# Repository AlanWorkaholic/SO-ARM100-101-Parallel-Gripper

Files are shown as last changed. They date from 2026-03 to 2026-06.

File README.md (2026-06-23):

# SO-ARM100/101 Parallel Gripper

<div align="center">

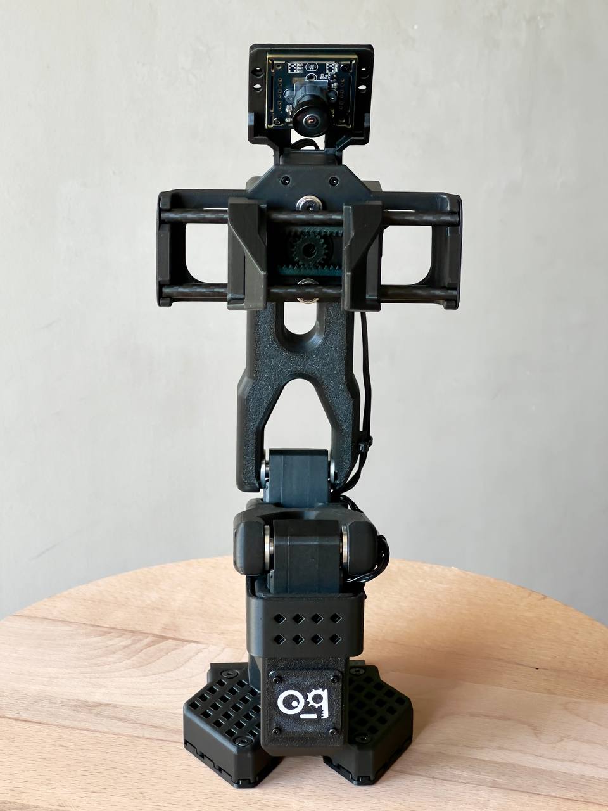
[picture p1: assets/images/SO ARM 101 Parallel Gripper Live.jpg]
SO-ARM101 Parallel Gripper (https://youtube.com/shorts/bSyXjgNGXZk)


**🎥 [Watch the gripper in action!](https://youtube.com/shorts/bSyXjgNGXZk)**

A lightweight 3D-printed parallel gripper designed by **[Robonine](https://robonine.com)** for the open-source SO-ARM100/101 robotic platform.





---

**Questions? We're here to help!**
📩 Email: [hello@robonine.com](mailto:hello@robonine.com)

</div>

---

## ✨ Key Features

| Feature | Description |
|---|---|
| **120N Gripping Force** | Reliable parallel jaw mechanism |
| **14 mm/s Speed** | Gripper operation speed |
| **84mm Full Stroke** | Wide opening for various objects |
| **0.5mm Repeatability** | High precision positioning |
| **Camera Compatible** | Supports RealSense, Orbbec, USB cameras |
| **3D Printable** | All parts print on standard FDM printers |
| **~$62 Total Cost** | Affordable open-source solution |
| **Easy Assembly** | 30-45 minutes with basic tools |

---

## 📸 Gallery

<div align="center">

### Gripper on SO-ARM101

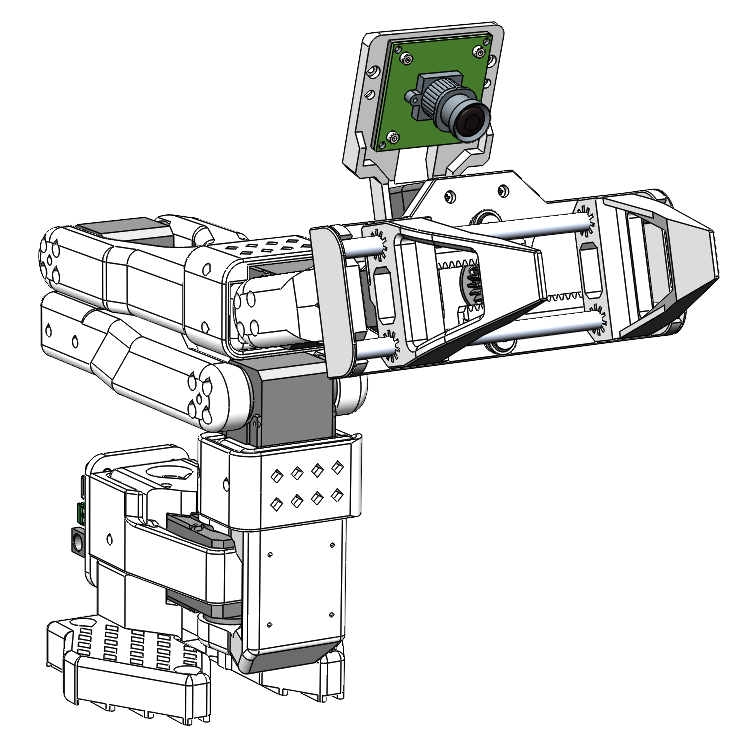
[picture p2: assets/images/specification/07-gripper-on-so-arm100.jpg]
Gripper mounted on SO-ARM101


*Follower gripper integrated with SO-ARM101 robot arm*

### Dimensions

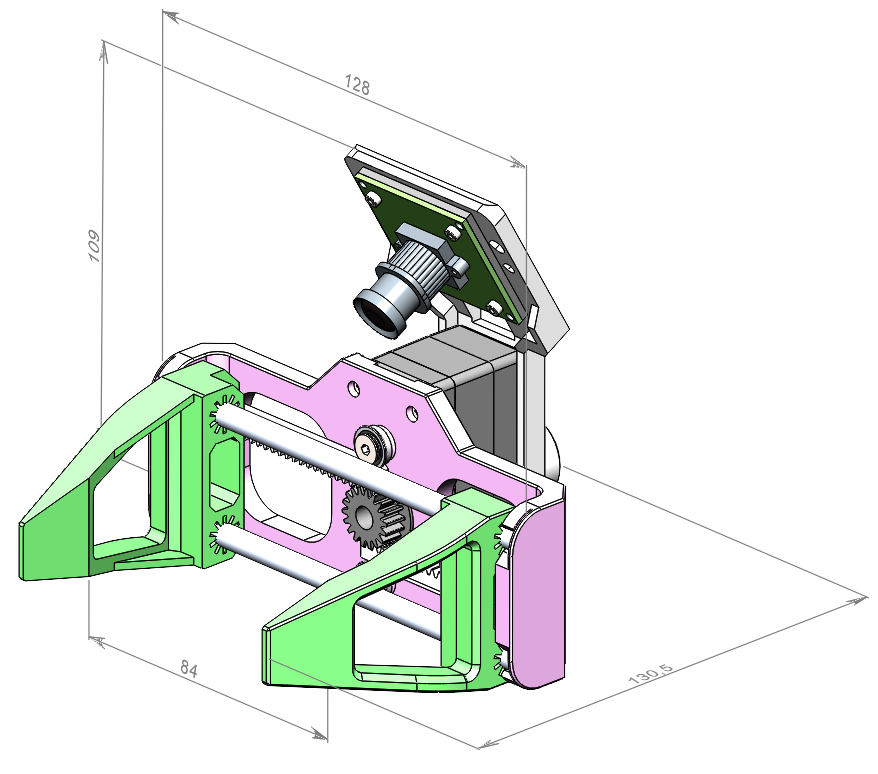
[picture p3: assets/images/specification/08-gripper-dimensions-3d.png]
Gripper dimensions


*128 × 109 × 130.5 mm, full stroke 84 mm*

</div>

---

## 📋 Specifications

### Gripper Parameters

| Parameter | Value |
|---|---|
| Maximum gripping force | **120 N** |
| Maximum gripping speed | **14 mm/s** |
| Full stroke | **84 mm** |
| Repeatability | **0.5 mm** |
| Assembly mass (PLA, 30% infill) | **170 g** |
| DOF | **1** |

### Dimensions

| Dimension | Value |
|---|---|
| Width | 128 mm |
| Depth | 130.5 mm |
| Height | 109 mm |

### Servo Parameters (Feetech STS3215)

| Parameter | Value |
|---|---|
| Operating Voltage | 12V |
| Stall torque | 30 kg·cm |
| Speed (no load) | 45 RPM |
| Encoder | Absolute magnetic 12-bit |
| Protocol | RS485/TTL up to 1 Mbps |
| Operating temperature | -20°C ~ 60°C |

---

## 📷 Camera Compatibility

The gripper supports multiple cameras via interchangeable camera holder:

| Camera | Type | Use Case |
|---|---|---|
| IMX335 5MP USB | RGB | Basic vision tasks |
| GC2093 2MP USB | RGB | Budget option |
| Orbbec Gemini 2 | RGB-D | 3D perception |
| RealSense D405 | RGB-D | Close-range depth |
| RealSense D435/D435i | RGB-D | General purpose |
| RealSense D455 | RGB-D | Long-range depth |

<div align="center">

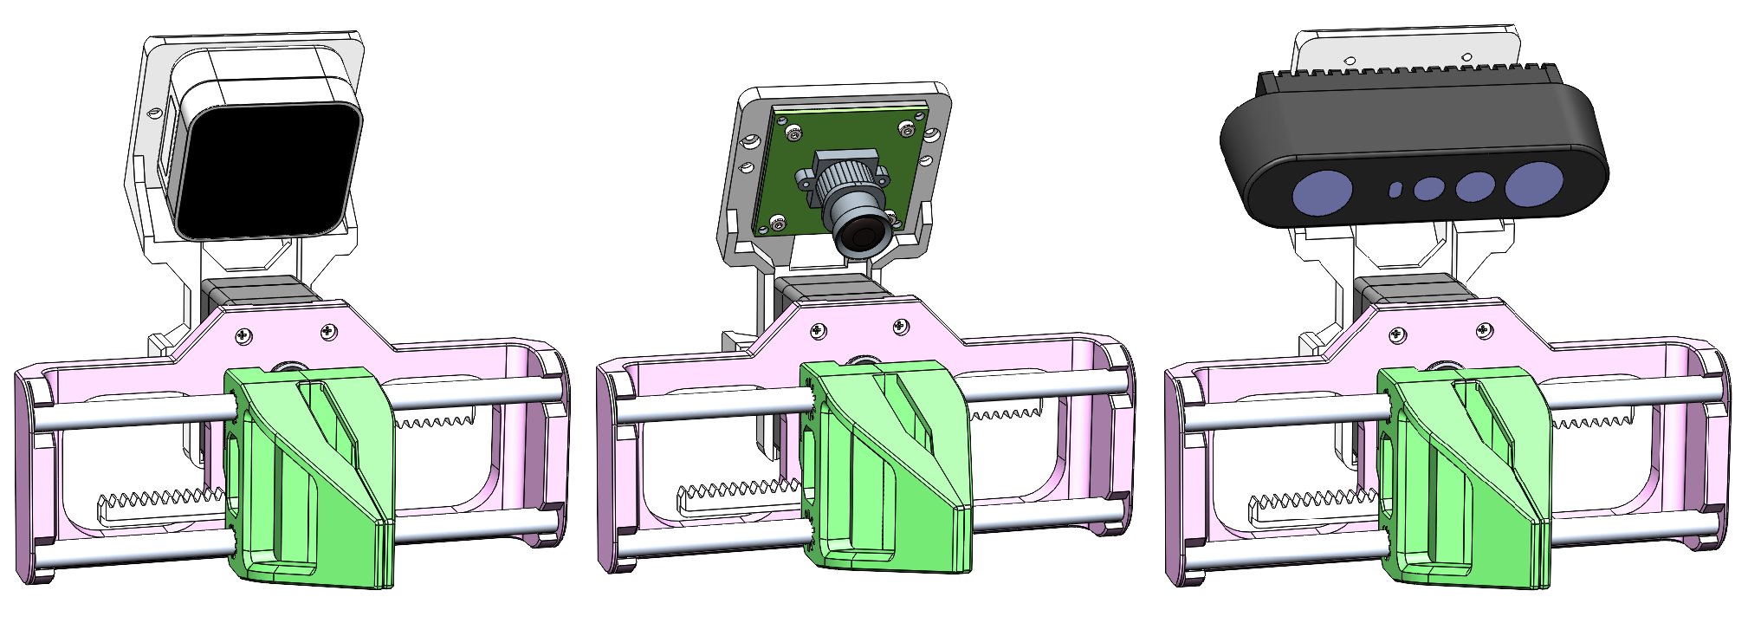
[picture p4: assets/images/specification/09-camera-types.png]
Different cameras mounted on gripper


*RealSense, USB camera module, Orbbec Gemini 2*

</div>

---

## 💰 Bill of Materials

**Total Cost: ~$62** ([Full BOM with Amazon links](docs/bom.md))

| Category | Components | Est. Cost |
|---|---|---|
| Electronics | Feetech STS3215 Servo + Servo Bus Adapter | ~$40 |
| Bearings | MF106ZZ (x2) | ~$2 |
| Aluminium/Carbon Tubes | D6x1×125mm (x2) | ~$4 |
| 3D Printing | 8 parts (~100-150g PLA) | ~$12 |
| Fasteners | M2/M4 screws, M2 nuts, M3 set screws | ~$3 |

---

## 🚀 Quick Start

### 1. Print the Parts (2-4 hours)

Download STL files from [`models/parts/`](models/). Compatible with popular printers like **Bambu Lab A1 mini**, **Prusa MINI+**, and any printer with ≥180×180mm bed.

| Part | Qty | Settings |
|---|:---:|---|
| Main frame (RB9.01.062.010) | 1 | 20% infill |
| Clamp (RB9.01.062.020) | 2 | 20% infill |
| Gear rack (RB9.01.062.030) | 2 | 100% infill |
| Gear (RB9.01.062.040) | 1 | 100% infill |
| Camera holder (RB9.01.060.074) | 1 | 20% infill |
| Holder (RB9.01.060.080) | 1 | 20% infill |
| Camera Spacer (RB9.01.060.090) | 1 | 20% infill |
| D405 holder (RB9.01.060.110) | 1 | 20% infill |

### 2. Order Components (1-2 days)

See [Bill of Materials](docs/bom.md) for direct Amazon links.

### 3. Assemble (30-45 minutes)

Follow the [Assembly Guide](docs/assembly-guide.md) with step-by-step images:

1. Mount gear on servo disc, install this assembly on servo
2. Insert servo cable
3. Using Feetech software move servo to its minimal position (move the slider in the software to the left)
4. Attach gear racks to clamps
5. Inserts the rods into both clamps
6. Install bearings on main frame and fix with srews
7. Snap the rods into the frame
8. Spread the clamps to the extreme positions on the left and right
9. Insert servo and fix it with screws
10. Attach Camera Spacer and UVC camera, fix with 4x screws and nuts M2 (optional)
11. Mount to robot arm (optional)

### 4. Software Setup

```bash
# Install STServo SDK
git clone https://github.com/FEETECH-RC/STServo_SDK_Python.git

# Install dependencies
pip install pyserial

# Run gripper control
python software/python/gripper_control.py
```

---

## 📁 Repository Structure

```
├── assets/
│   └── images/
│       ├── assembly/          # Assembly step images
│       └── specification/     # Technical drawings
├── docs/
│   ├── assembly-guide.md                # Step-by-step assembly
│   ├── bom.md                           # Bill of materials with links
│   ├── Parallel gripper by Robo9.pdf    # Gripper product specification
│   ├── quick-start.md                   # Getting started guide
│   ├── SO-ARM101 by Robo9.pdf           # SO-ARM101 product specification
│   └── specifications.md               # Technical specifications
├── models/
│   ├── parts/                              # Individual STL files
│   └── Follower_Gripper_180x180_BedSize.STL  # Complete assembly (180×180mm bed)
├── simulation/
│   ├── README.md                  # Simulation overview
│   ├── gazebo/                    # Gazebo guide
│   ├── mujoco/                    # MuJoCo guide
│   ├── webots/                    # Webots guide
│   ├── coppeliasim/               # CoppeliaSim guide
│   ├── isaac_sim/                 # Isaac Sim guide
│   └── so_arm_101_description/    # ROS2 package (URDF, launch, Docker)
├── software/
│   └── python/                # Control software
└── examples/                  # Usage examples
```

---

## 📖 Documentation

| Document | Description |
|---|---|
| [Quick Start Guide](docs/quick-start.md) | Get running in 30 minutes |
| [Assembly Guide](docs/assembly-guide.md) | Step-by-step with images |
| [Bill of Materials](docs/bom.md) | Parts list with Amazon links |
| [Specifications](docs/specifications.md) | Technical details |
| [3D Models](models/README.md) | Print settings and files |
| [Parallel Gripper Product Spec (PDF)](docs/Parallel%20gripper%20by%20Robo9.pdf) | Parallel gripper product specification by Robo9 |
| [SO-ARM101 Product Spec (PDF)](docs/SO-ARM101%20by%20Robo9.pdf) | SO-ARM101 robot arm product specification by Robo9 |

---

## 🔧 Hardware Requirements

### Electronics
- 1× Feetech STS3215 Servo Motor
- 1× Bus Servo Adapter Board (Waveshare)

### Mechanical
- 2× MF106ZZ Bearings (6×10×3 mm)
- 2× Aluminium/Carbon Tubes D6x1×125 mm

### Fasteners
- 2× M4×8 DIN 7991 screws
- 4x M2x8 DIN 912 screws
- 4× M2 DIN 934 nuts
- 4× M3×4 DIN 913 set screws

### Tools Required
- Phillips head screwdriver (PH1)
- Hex keys M2 (H1.5) and M4 (H2.5)

---

## 🖥️ Simulation

The SO-ARM101 can be simulated in 5 physics engines using a ROS2 description package with a single parameterized URDF. No ROS2 installation required -- Docker handles everything.

<div align="center">

| Gazebo (Ignition Fortress) | MuJoCo |
|:-:|:-:|
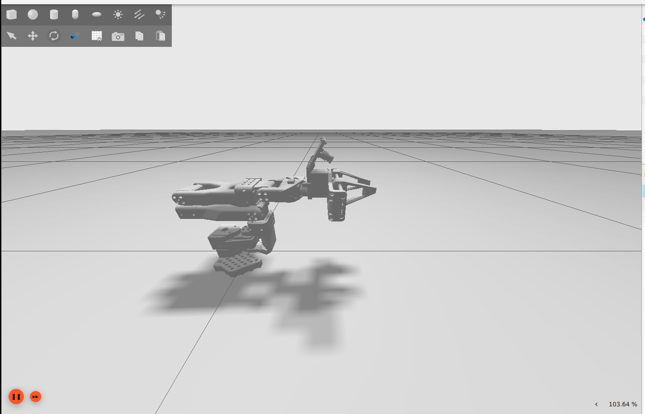
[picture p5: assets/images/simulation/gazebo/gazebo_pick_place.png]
SO-ARM-101 in Gazebo
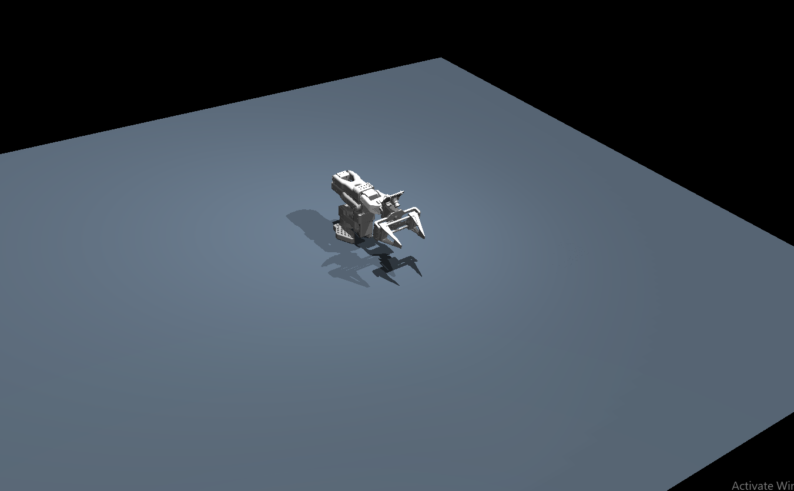
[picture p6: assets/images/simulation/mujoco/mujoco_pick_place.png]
SO-ARM-101 in MuJoCo
|  |  |

</div>

| Simulator | Status | Docker |
|---|---|---|
| [Gazebo](simulation/gazebo/README.md) | Ready | `docker compose run gazebo` |
| [MuJoCo](simulation/mujoco/README.md) | Ready | `docker compose run mujoco` |
| [Webots](simulation/webots/README.md) | Unstable | `docker compose run webots` |
| [CoppeliaSim](simulation/coppeliasim/README.md) | Not tested | External simulator |
| [NVIDIA Isaac Sim](simulation/isaac_sim/README.md) | Not tested | External simulator |

**Quick start (Docker):**

```bash
cd simulation/so_arm_101_description
docker compose run gazebo    # or mujoco, webots
```

See the [Simulation Guide](simulation/README.md) for full setup, architecture details, and robot commanding.

---

## 🤝 Contributing

We welcome contributions! Please feel free to:
- 🐛 Report bugs and issues
- 💡 Suggest new features
- 🔧 Submit pull requests
- 📖 Improve documentation

---

## 📄 License

This project is licensed under the GPL-3.0 License - see the [LICENSE](LICENSE) file for details.

---

## 🔗 Links

- [Feetech STS3215 Servo](https://www.feetechrc.com/525603.html)
- [Waveshare Bus Servo Adapter](https://www.waveshare.com/bus-servo-adapter-a.htm)
- [STServo Python SDK](https://github.com/FEETECH-RC/STServo_SDK_Python)

---

## 👥 Engineering Team

| Name | Role | Contact |
|---|---|---|
| **Boris Kotov** | Software Engineer | [Telegram](https://t.me/bkotov) |
| **Alan Subin** | Design Engineer | [LinkedIn](https://www.linkedin.com/in/alan-subin/) |

---

<div align="center">

**Built for the robotics community by [Robonine](https://robonine.com)** 🤖

**Questions? We're here to help!**
📩 Email: [hello@robonine.com](mailto:hello@robonine.com)

</div>

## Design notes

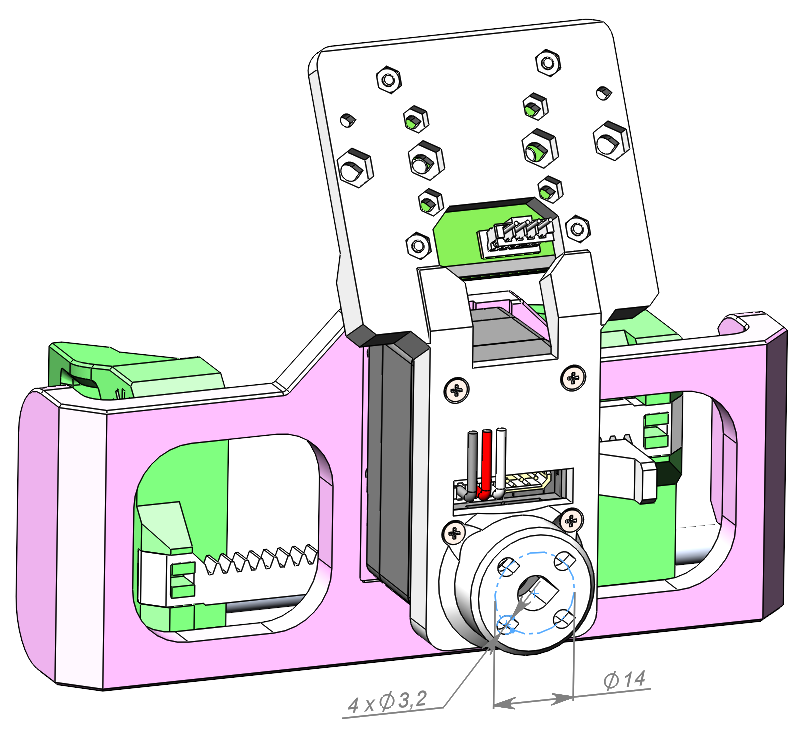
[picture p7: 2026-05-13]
assets/images/specification/03-mounting-interface.jpg

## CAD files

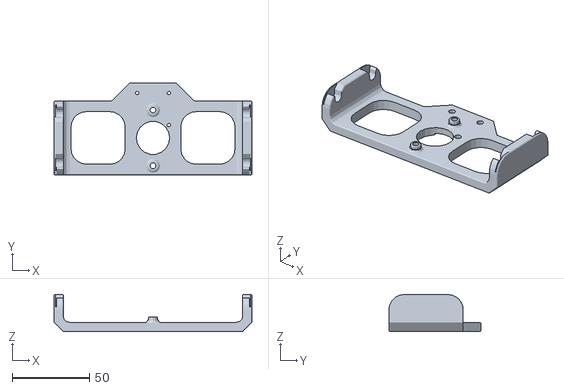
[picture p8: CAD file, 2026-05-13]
models/parts/RB9.01.062.010 Main frame.STL
128.0 x 59.5 x 24.0

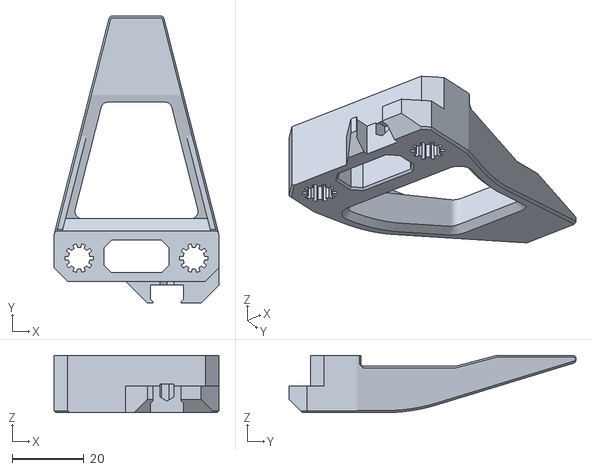
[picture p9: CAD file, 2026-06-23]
models/parts/RB9.01.062.021 (D6.0) Clamp.STL
46.0 x 80.0 x 16.0

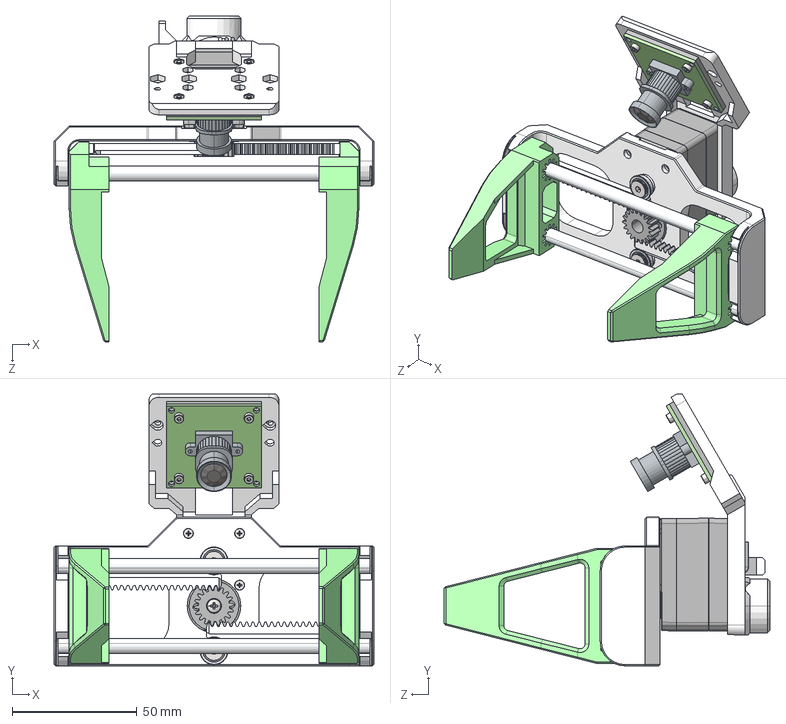
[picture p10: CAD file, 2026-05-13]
models/RB9.01.062.000 Gripper.STEP
128.0 x 108.8 x 130.5 mm
RB9.01.062.010 Main frame_125 follower
RB9.01.062.020 Clamp x 2
RB9.01.062.030 Gear rack_m0.8 x 2
RB9.01.062.040 Gear for gripper_ISO - Spur gear 0.8M 18T 20PA 5FW ---S18B10H8L6.0S1
RB9.01.062.070 Camera holder_follower + camera
RB9.01.060.090 Camera spacer
Rod d6_125 x 2
ZK_122^STS3215_Servo
SG-ZIJI_15^STS3215_Servo
XG-ZIJI_16^STS3215_Servo
Main Wheel^STS3215_Servo
pan head cross recess screw_din_DIN EN ISO 7045 - M3 x 4 - Z - 4N
0050375033_｢ｯ燿｢ｮ
GC2093 2MP USB Camera Module_IMX335 5MP USB Camera
Bearing_MF106 10å6å3 x 2
countersunk flat head cross recess screw_din_DIN EN ISO 7046-1 - M2 x 8 - Z - 8N x 3
socket countersunk head screw_din_DIN 7991 - M4 x 8 --- 8N x 2
hex nut style 1 gradeab_din_Hexagon Nut ISO 4032 - M2 - D - N x 4
socket head cap screw_din_DIN 912 M2 x 8 --- 8N x 4

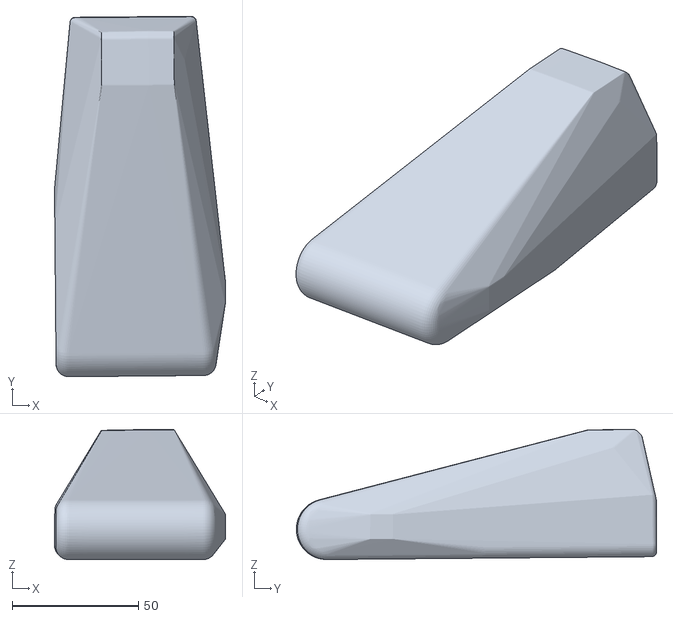
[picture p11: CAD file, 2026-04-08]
simulation/so_arm_101_description/meshes/collision/link2_1.stl
67.7 x 142.7 x 51.5

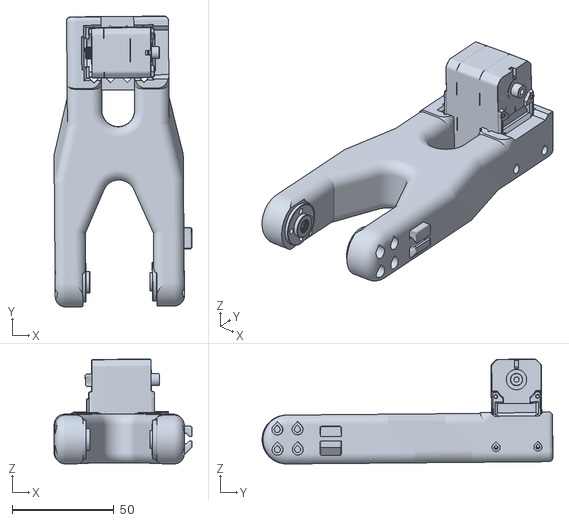
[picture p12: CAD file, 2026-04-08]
simulation/so_arm_101_description/meshes/visual/link2_1.stl
67.7 x 142.7 x 51.5

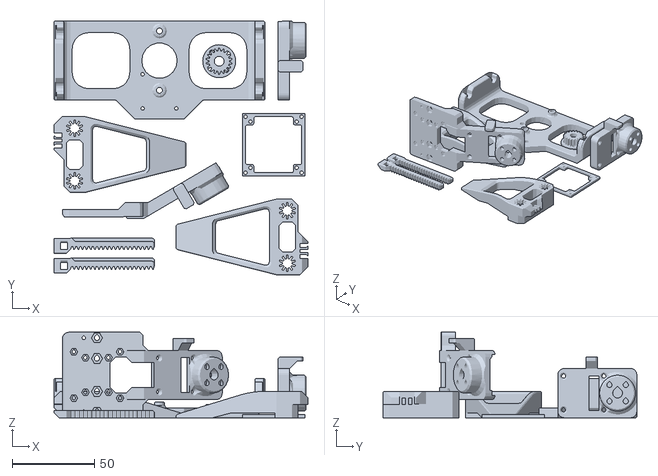
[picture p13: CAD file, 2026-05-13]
models/Follower gripper (165x165 bed size).STL
154.1 x 154.0 x 52.0

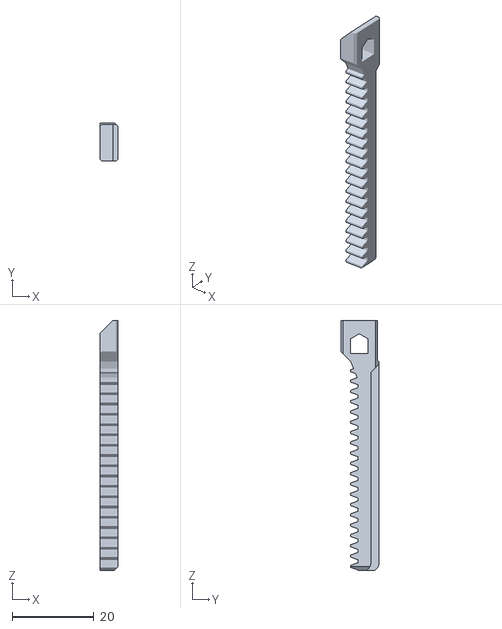
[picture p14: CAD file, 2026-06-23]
models/parts/RB9.01.062.031 Gear rack.STL
4.50 x 9.35 x 61.0

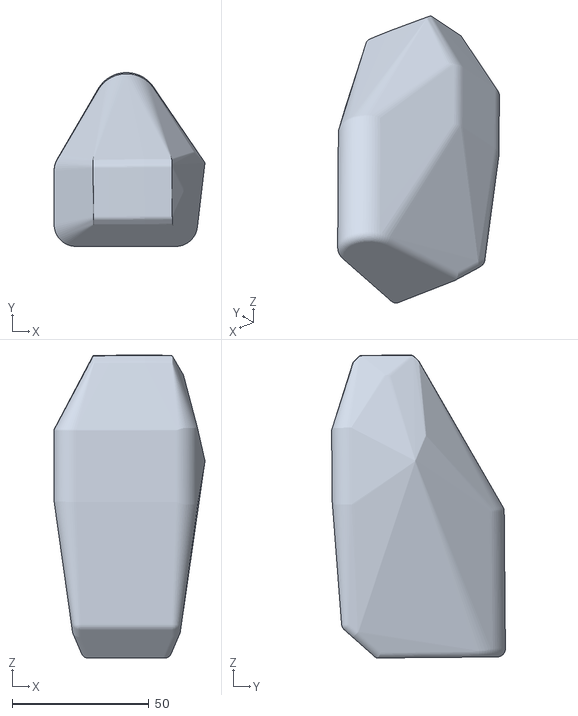
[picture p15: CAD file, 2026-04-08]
simulation/so_arm_101_description/meshes/collision/link1_1.stl
55.1 x 63.5 x 110.7

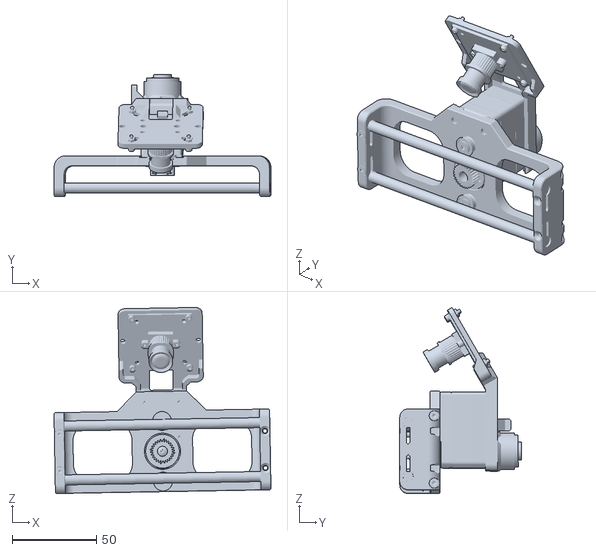
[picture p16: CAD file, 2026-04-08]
simulation/so_arm_101_description/meshes/visual/link5_1.stl
128.8 x 72.5 x 110.5

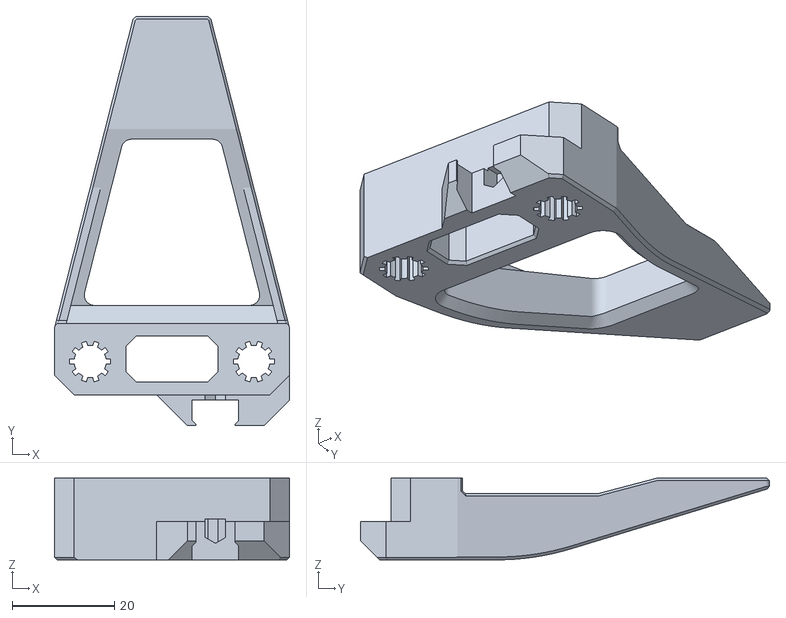
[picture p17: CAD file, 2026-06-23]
models/parts/RB9.01.062.021 (D6.3) Clamp.STL
46.0 x 80.0 x 16.0

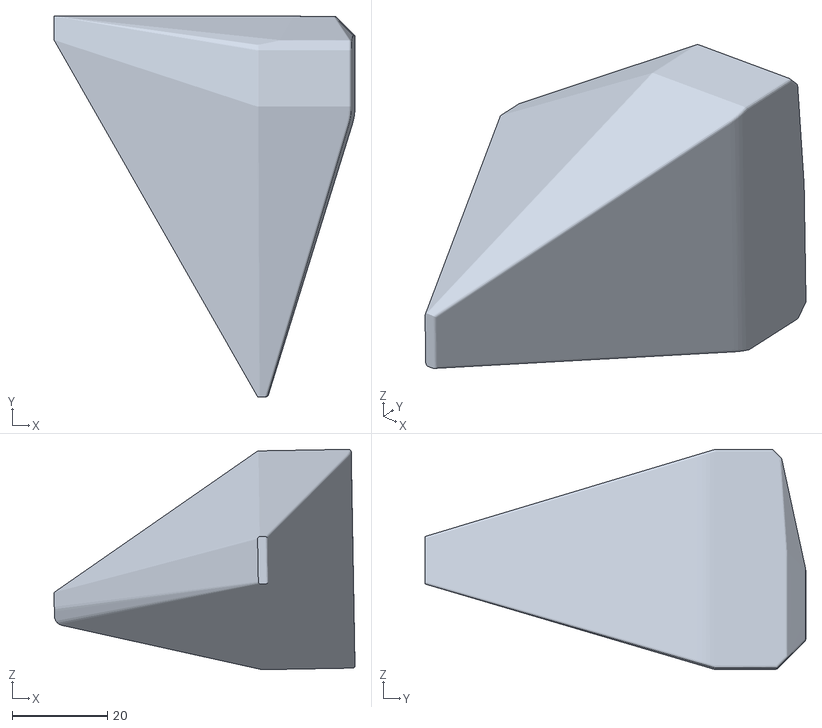
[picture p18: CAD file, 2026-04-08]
simulation/so_arm_101_description/meshes/collision/clamp_1.stl
63.3 x 80.0 x 46.3

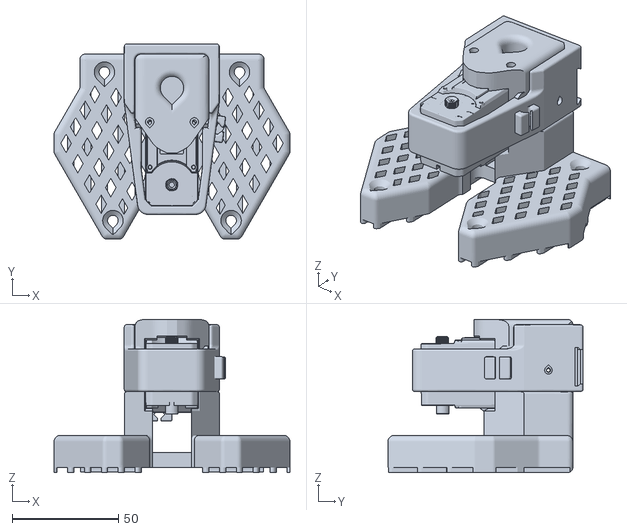
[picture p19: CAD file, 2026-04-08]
simulation/so_arm_101_description/meshes/visual/base_link.stl
110.9 x 91.8 x 72.0

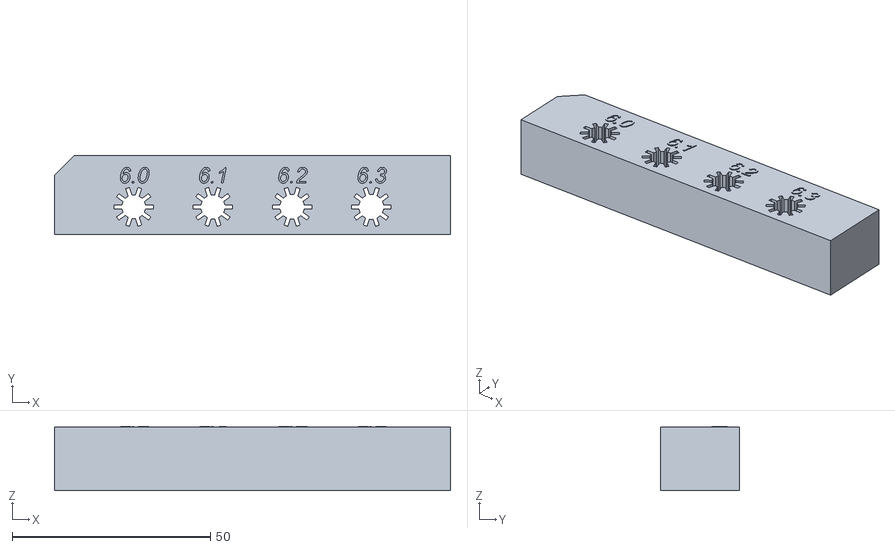
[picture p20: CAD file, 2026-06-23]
models/parts/Gripper test plate star holes 6.0-6.3.STL
100.0 x 20.0 x 16.2

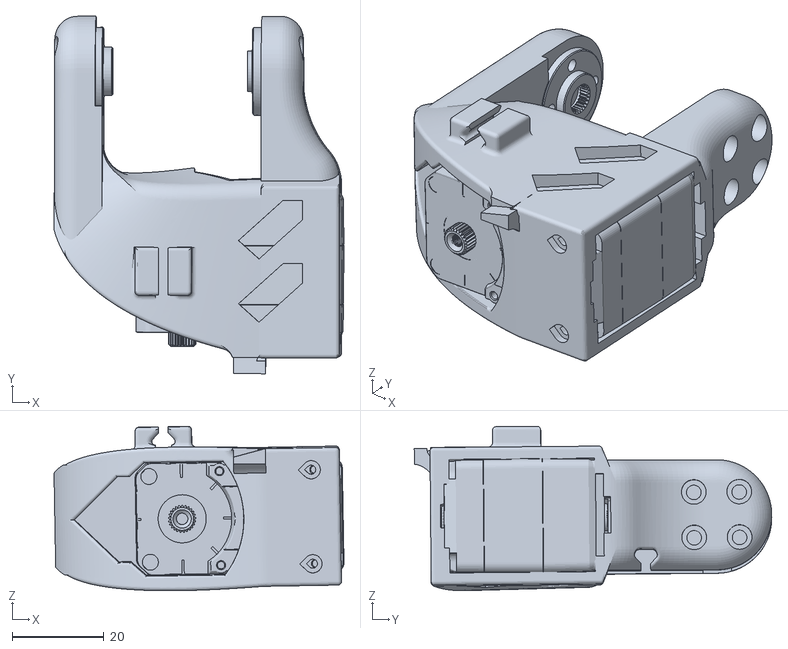
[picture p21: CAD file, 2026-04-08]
simulation/so_arm_101_description/meshes/visual/link4_1.stl
63.2 x 78.0 x 35.9

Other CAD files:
simulation/so_arm_101_description/meshes/collision/clamp_2.stl
models/parts/RB9.01.062.021 (D6.2) Clamp.STL
simulation/so_arm_101_description/meshes/collision/link4_1.stl
simulation/so_arm_101_description/meshes/visual/clamp_2.stl
models/parts/RB9.01.060.074 Camera holder.STL
models/parts/RB9.01.060.080 Holder.STL
models/parts/RB9.01.060.090 Camera spacer.STL
models/parts/RB9.01.060.110 D405 holder.STL
models/parts/RB9.01.062.020 Clamp.STL
models/parts/RB9.01.062.021 (D6.1) Clamp.STL
models/parts/RB9.01.062.030 Gear rack.STL
models/parts/RB9.01.062.040 Gear.STL
models/parts/RB9.01.062.100 Nail.STL
simulation/so_arm_101_description/meshes/collision/base_link.stl
simulation/so_arm_101_description/meshes/collision/link3_1.stl
simulation/so_arm_101_description/meshes/collision/link5_1.stl
simulation/so_arm_101_description/meshes/visual/clamp_1.stl
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

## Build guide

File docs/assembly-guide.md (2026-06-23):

# Assembly Guide for Follower Gripper SO-ARM101

This guide provides step-by-step instructions for assembling the parallel gripper. Follow these steps carefully to ensure proper operation.

## Required Tools

- Phillips head screwdriver PH1
- Hex keys M2 (H1.5) and M4 (H2.5)

---

## Step 1: Install Gear on Servo

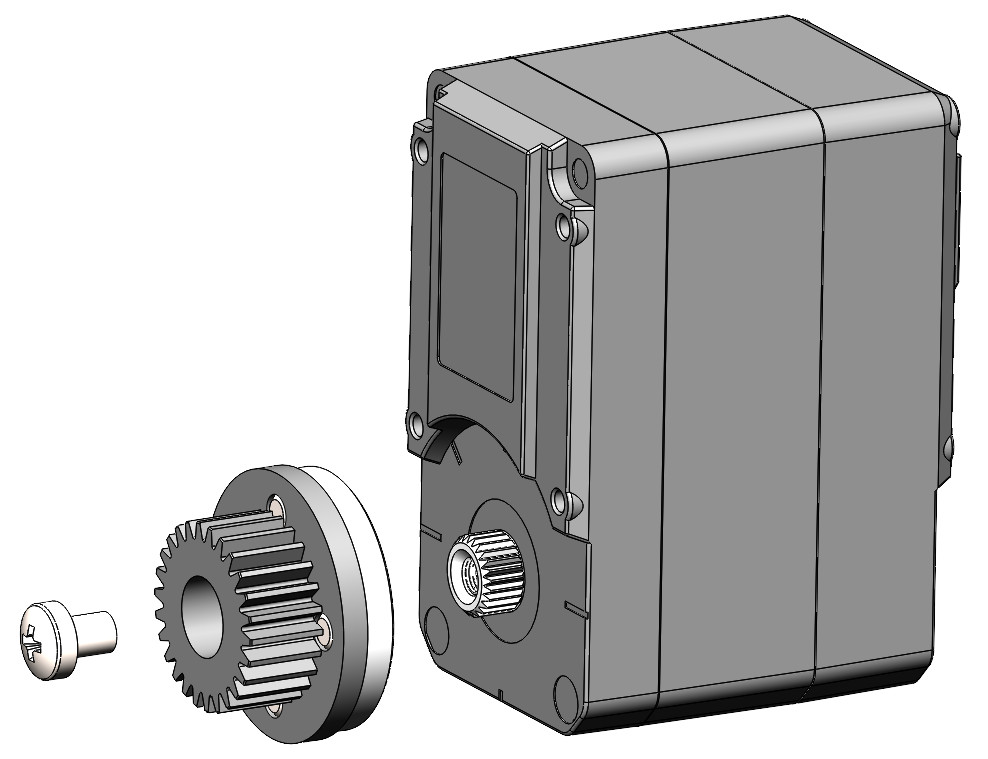
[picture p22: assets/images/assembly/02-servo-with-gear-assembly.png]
Servo with gear assembly


**Components needed:**
- 1x Feetech STS3215 Servo
- 1x Gear  (RB9.01.062.040)
- 1x Servo disk (from servo kit)
- 1x Servo mounting screw M3x6 (from servo kit)
- 4x Set Screw DIN 913 M3x4

**Instructions:**
1. Place Gear for Gripper on Servo disk and tighten 4x Set Screws M3x4 in the direction from Servo disk to Gear. Make sure that no gap appears between Disk and Gear when tightening the screws.
2. Mount the gear assembly onto the servo output shaft.
3. Secure with the screw M3x6 provided in the servo kit.

---

## Step 2: Servo Positioning and Torque Limit

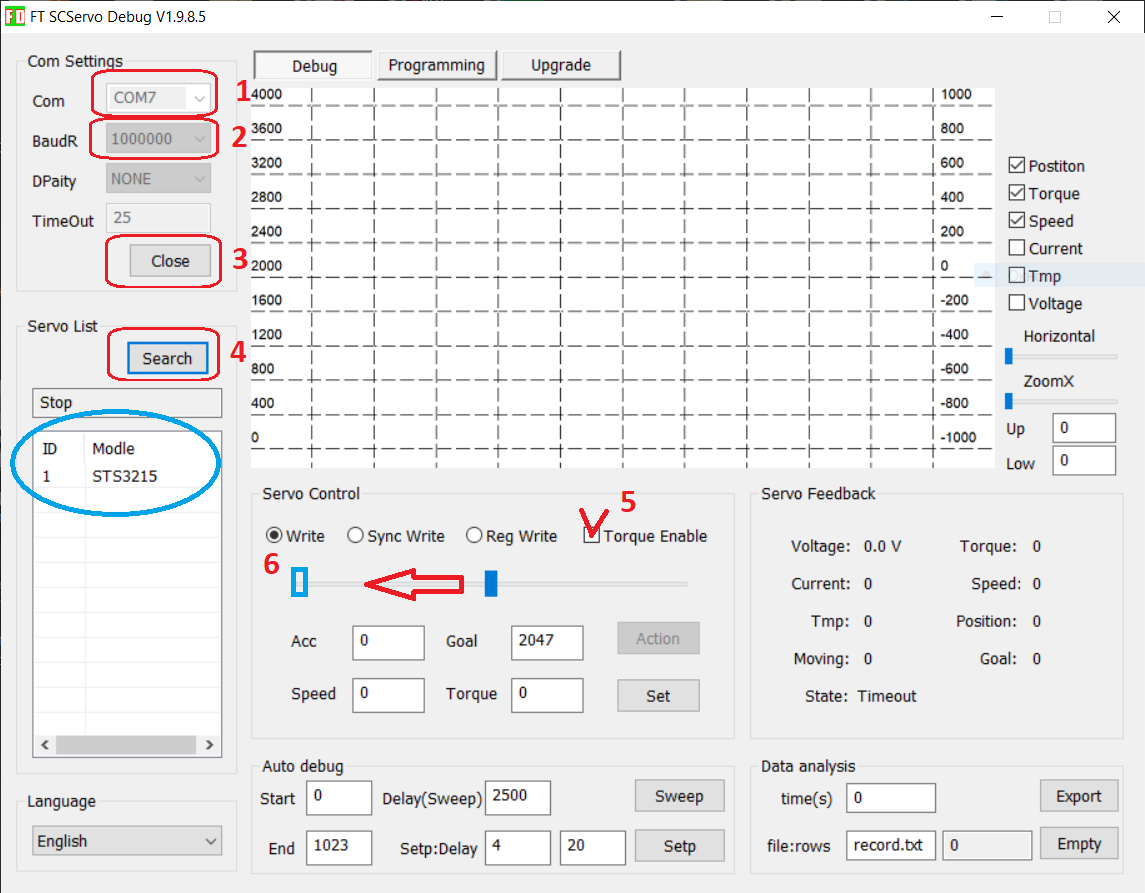
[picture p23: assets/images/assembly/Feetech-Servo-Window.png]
Servo positioning


**Components needed:**
- 1x Serial Bus Servo Board and Cables

**Instructions for Windows users:**
1. Connect Servo to Serial Bus Servo Board, connect Board to PC by USB.
2. Run FD.exe from [`software/python/`](../software/).
3. Choose your COM port, select BaudRate 1 000 000, push buttons "Open" and after "Search".
4. Below from the list select your servo.
5. Check the box to enable torque on servo.
6. Move the slider to the left.

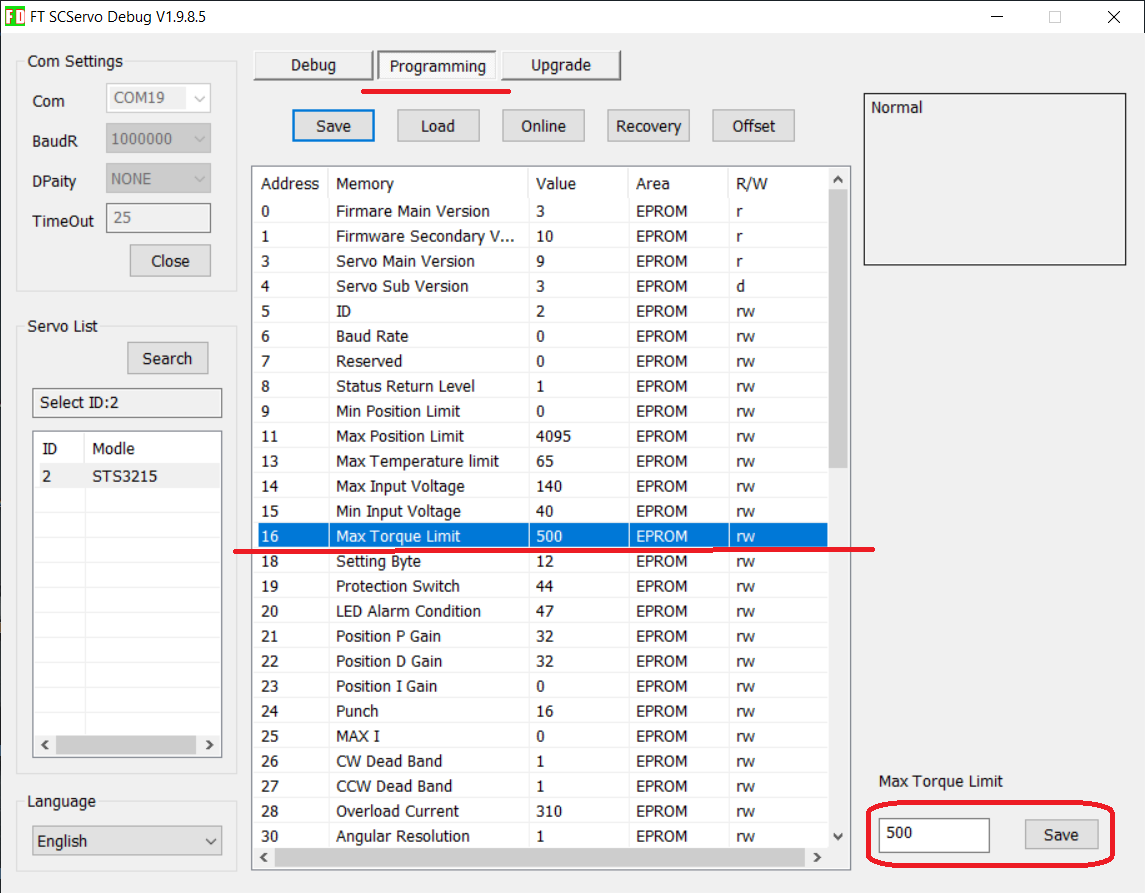
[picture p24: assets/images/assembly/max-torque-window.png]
Max torque limit


7. Switch the window to a tab "Programming".
8. Choose parameter "Max Torque Limit", set it to 500 ans press "Save".

---

## Step 3: Clamps

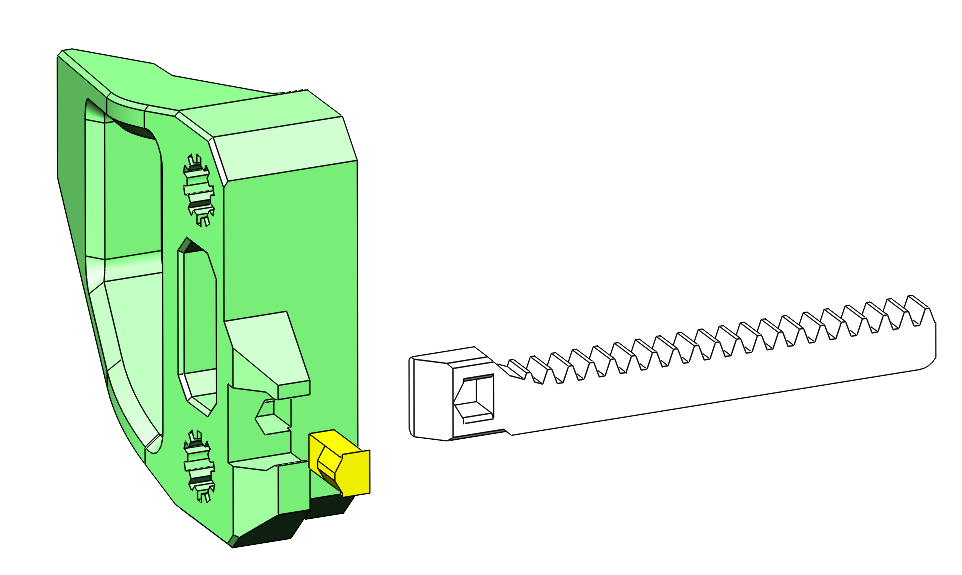
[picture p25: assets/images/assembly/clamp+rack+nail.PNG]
Clamps


**Components needed:**
- 2x Clamps (RB9.01.062.021)
- 2x Gear racks (RB9.01.062.031)
- 2x Nails (RB9.01.062.100)

**Instructions:**
1. Insert gear racks in clamps from side direction.
2. Then insert nails from back direction.

---

## Step 4: Rods

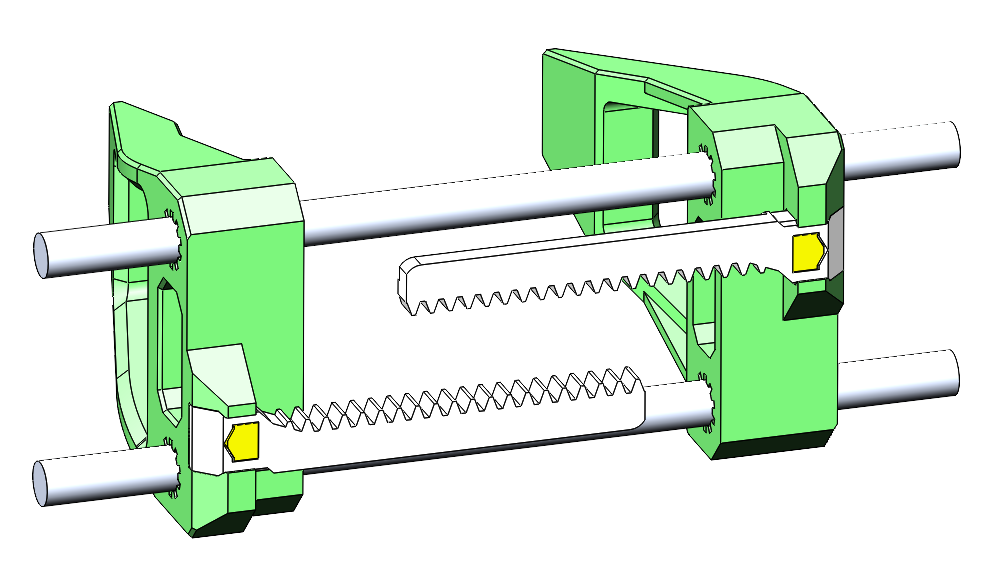
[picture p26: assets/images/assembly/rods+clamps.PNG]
Rods


**Components needed:**
- 2x Rods D6x125mm

**Instructions:**
1. Insert the rods into both clamps. If you ordered rods/tubes longer than 125 mm you need to cut them to this length.

---

## Step 5: Install Bearings on Main Frame

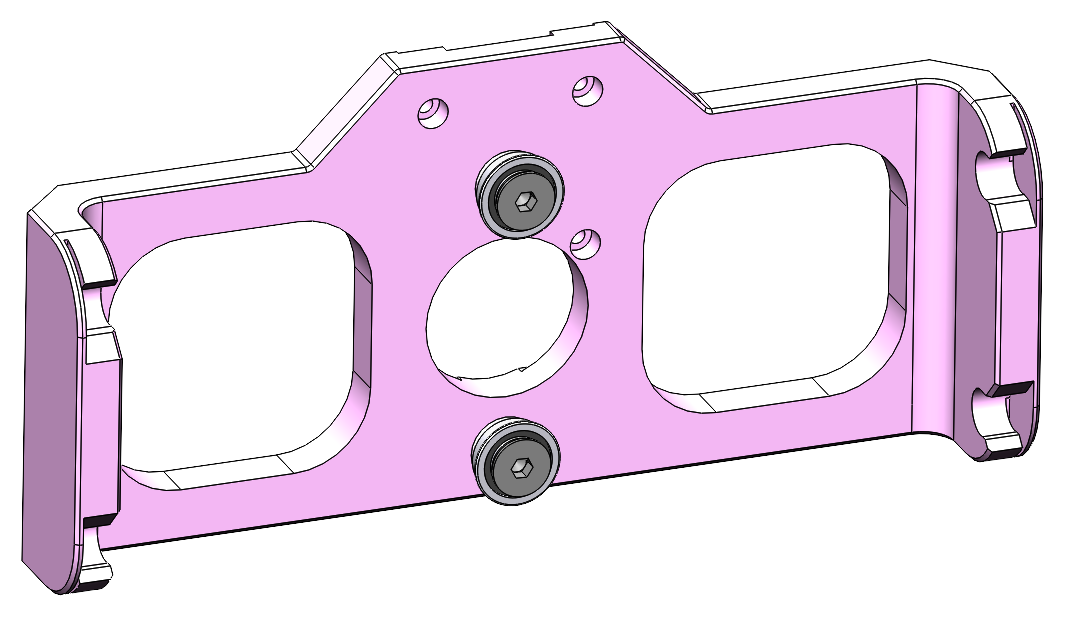
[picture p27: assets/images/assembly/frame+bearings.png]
Bearings installed on main frame


**Components needed:**
- 2x MF106ZZ Bearings (10x6x3 mm)
- 2x M4x8 DIN 7991 screws

**Instructions:**
1. Insert the 2x MF106ZZ bearings into their designated positions on the main frame. Bearing flange should face up.
2. Secure each bearing with screw M4x8.

---

## Step 6: Connection of rods and frame

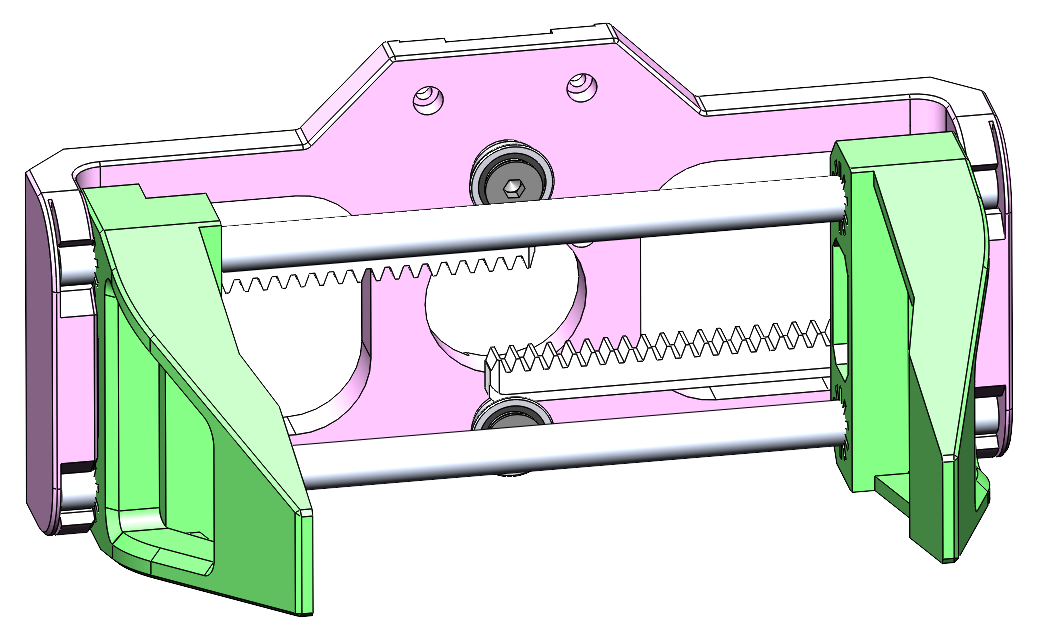
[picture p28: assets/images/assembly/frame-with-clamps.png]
Connection of rods and main frame


**Instructions:**
1. Snap the rods into the frame.
2. Spread the clamps to the extreme positions on the left and right.

---

## Step 7: Mount Servo on Main Frame

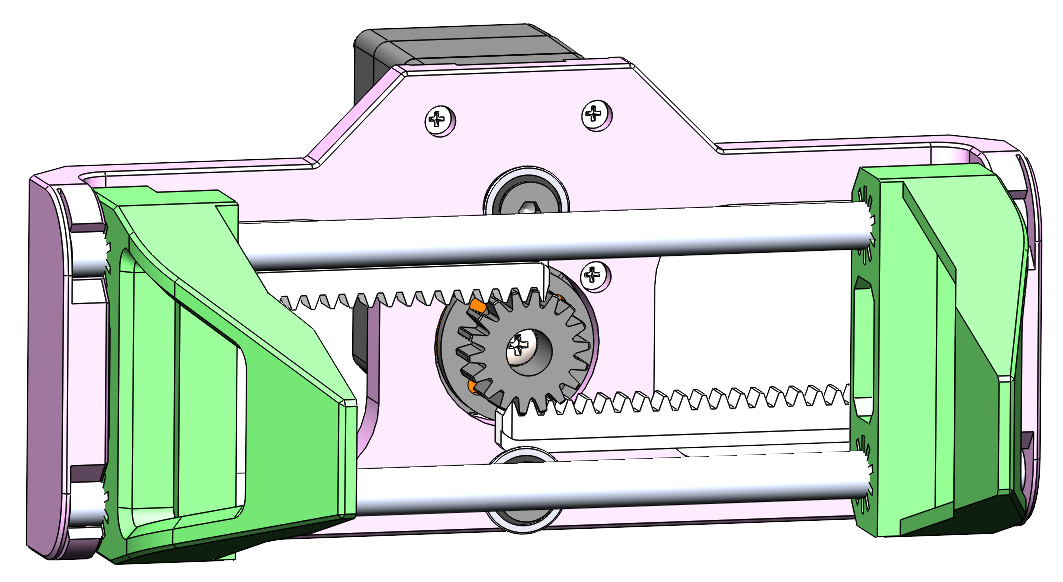
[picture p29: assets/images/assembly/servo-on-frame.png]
Servo mounted on main frame


**Components needed:**
- 3x Self-tapping screws (from servo kit)

**Instructions:**
1. Position the servo on the main frame and align mounting holes.
2. Secure the servo using 3x self-tapping screws from the servo kit.

---

## Step 8: Gripper Holder Attachment

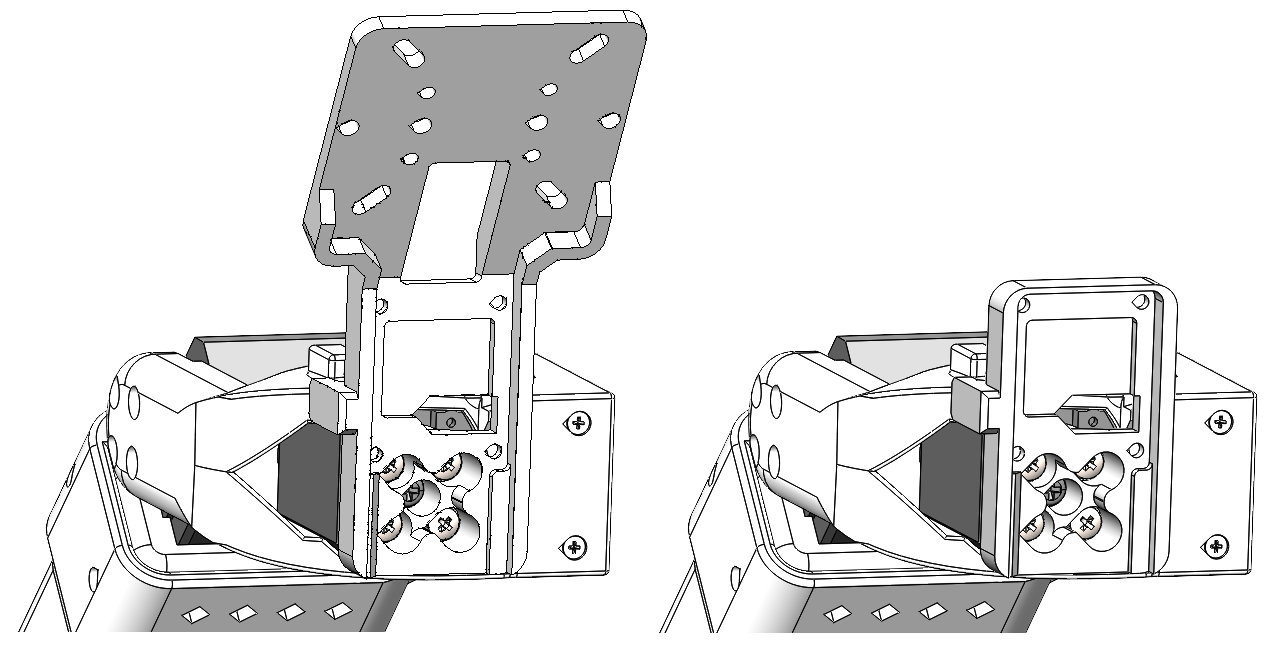
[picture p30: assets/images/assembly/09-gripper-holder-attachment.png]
Gripper holder attachment


**Components needed:**
- 1x Camera holder (RB9.01.060.074) or Holder (RB9.01.060.080)
- 1x SO-ARM101
- 4x M3x6 Screws (from servo kit)
- 4x Self-tapping screws (from servo kit)

**Instructions:**
1. If you plan to use Gripper with camera then attach Camera holder, if you plan to use Gripper without camera then attach Holder to the Wrist Joint horn of SO-ARM101 and fix with 4x M3x6 screws
2. Attach the Parallel Gripper to the Camera holder or Holder and fix with 4x self-tapping screws
3. Connect cable from the Parallel Gripper to servo №5 of SO-ARM101

---

## Step 9: Camera Attachment (optional)

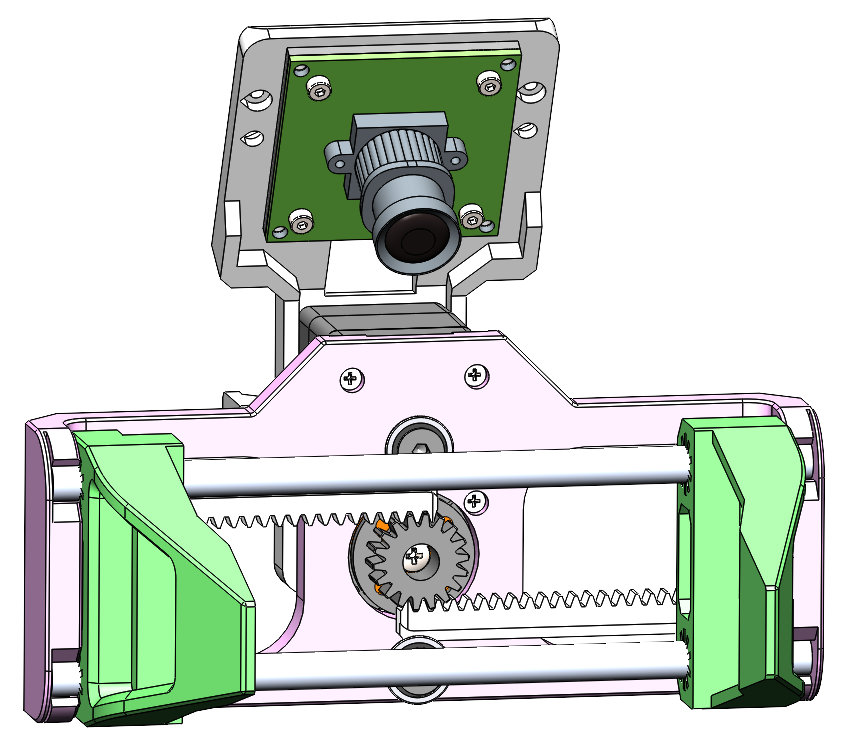
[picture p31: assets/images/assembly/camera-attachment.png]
Camera attachment


**Components needed:**
- 1x UVC Camera with mount holes at 28x28 mm
- 1x Camera Spacer (RB9.01.060.090)
- 4x M2x8 Screws
- 4x M2 Nuts

**Instructions:**
1. Put 4x nuts M2 from the back side of Camera Holder.
2. Put Camera Spacer and Camera from the front side and fix with 4x screws M2x8.

---
## Assembly Complete!

Assembled SO-ARM101 with Follower Gripper

Congratulations! Your SO-ARM101 is now assembled and ready for use.

### Next Steps
- Test gripper operation before use

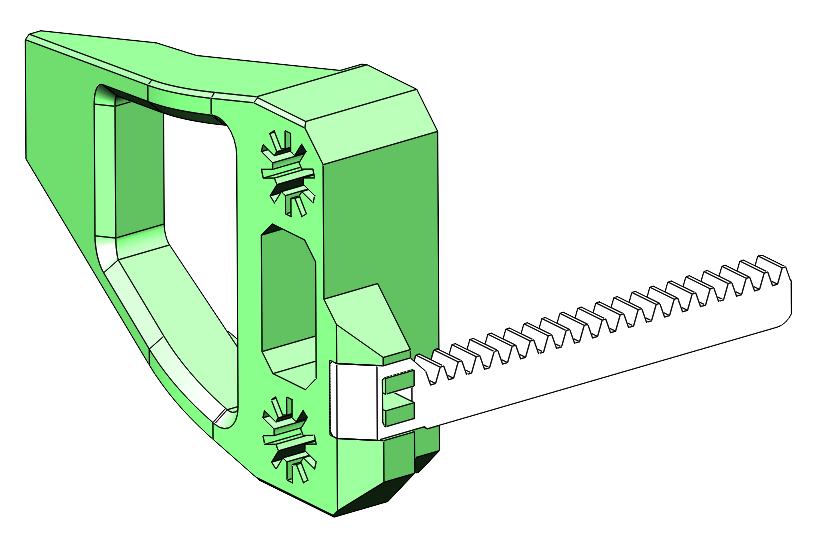
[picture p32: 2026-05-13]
assets/images/assembly/clamp+rack.png

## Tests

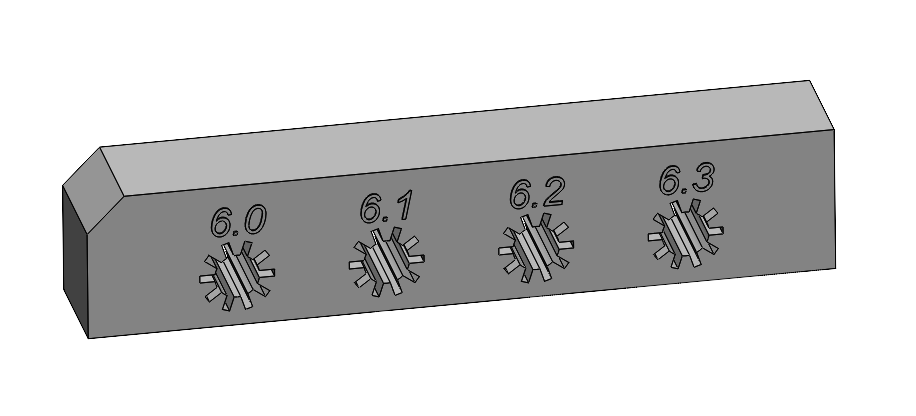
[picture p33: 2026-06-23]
assets/images/assembly/rod-test-plate.PNG

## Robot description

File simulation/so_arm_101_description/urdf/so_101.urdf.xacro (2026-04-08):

<?xml version="1.0" ?>
<robot name="so_101" xmlns:xacro="http://www.ros.org/wiki/xacro">

  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
  <xacro:arg name="sim_backend" default="gazebo"/>

  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
  <xacro:include filename="$(find so_arm_101_description)/urdf/materials.xacro"/>
  <xacro:include filename="$(find so_arm_101_description)/urdf/so_101.ros2_control.xacro"/>

  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
  <mujoco>
    <compiler meshdir="$(find so_arm_101_description)/meshes/collision"/>
  </mujoco>

  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

  <link name="world"/>
  <joint name="world_to_base" type="fixed">
    <parent link="world"/>
    <child link="base_link"/>
    <origin xyz="0 0 0" rpy="0 0 0"/>
  </joint>

  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

  <link name="base_link">
    <inertial>
      <origin xyz="-7.395983749131527e-05 0.018688778123587116 0.031975817456183726" rpy="0 0 0"/>
      <mass value="0.2092095548721987"/>
      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
    </inertial>
    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
  </link>

  <link name="link1_1">
    <inertial>
      <origin xyz="-6.74951590711253e-05 -0.030490405697529033 0.053766555610065915" rpy="0 0 0"/>
      <mass value="0.24184654503223657"/>
      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
    </inertial>
    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
  </link>

  <link name="link2_1">
    <inertial>
      <origin xyz="-0.018388577871412994 0.06261038358877268 0.0010120440807449838" rpy="0 0 0"/>
      <mass value="0.98611438366224"/>
      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
    </inertial>
    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
  </link>

  <link name="link3_1">
    <inertial>
      <origin xyz="-0.017751520535904237 -0.06544031690248904 -0.0001729613192295032" rpy="0 0 0"/>
      <mass value="0.9031154796125306"/>
      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
    </inertial>
    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
  </link>

  <link name="link4_1">
    <inertial>
      <origin xyz="-0.014388616159181473 -0.028802697165152366 -0.00020561897946119734" rpy="0 0 0"/>
      <mass value="0.31773533805976817"/>
      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
    </inertial>
    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
  </link>

  <link name="link5_1">
    <inertial>
      <origin xyz="-0.0005839285183169068 -0.04153912948671028 0.01505583353882603" rpy="0 0 0"/>
      <mass value="0.5561721109318601"/>
      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
    </inertial>
    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
  </link>

  <link name="clamp_1">
    <inertial>
      <origin xyz="0.0601695113719365 0.14480677890200364 0.1844826866723634" rpy="0 0 0"/>
      <mass value="0.15381179772652928"/>
      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
    </inertial>
    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
  </link>

  <link name="clamp_2">
    <inertial>
      <origin xyz="-0.0800042161303889 0.1470101120878245 0.18506826370370444" rpy="0 0 0"/>
      <mass value="0.15381179772652928"/>
      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
    </inertial>
    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
  </link>

  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
  <joint name="base_link_to_link1" type="revolute">
    <origin xyz="-9.9e-05 -0.007243 0.027983" rpy="0 0 0"/>
    <parent link="base_link"/>
    <child link="link1_1"/>
    <axis xyz="-0.0 -0.008727 0.999962"/>
    <limit lower="-2.094395" upper="2.094395" effort="1.5" velocity="5.236"/>
    <dynamics damping="0.1" friction="0.05"/>
    <safety_controller soft_lower_limit="-2.044" soft_upper_limit="2.044" k_position="100" k_velocity="10"/>
  </joint>

  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
  <joint name="link1_to_link2" type="revolute">
    <origin xyz="0.020891 -0.031313 0.091377" rpy="0 0 0"/>
    <parent link="link1_1"/>
    <child link="link2_1"/>
    <axis xyz="-0.999962 -0.008726 -7.6e-05"/>
    <limit lower="-3.228859" upper="0.174533" effort="1.5" velocity="5.236"/>
    <dynamics damping="0.1" friction="0.05"/>
    <safety_controller soft_lower_limit="-3.179" soft_upper_limit="0.125" k_position="100" k_velocity="10"/>
  </joint>

  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
  <joint name="link2_to_link3" type="revolute">
    <origin xyz="0.00151 0.112435 0.029417" rpy="0 0 0"/>
    <parent link="link2_1"/>
    <child link="link3_1"/>
    <axis xyz="-0.999924 -0.00865 -0.008802"/>
    <limit lower="0.0" upper="3.316126" effort="1.5" velocity="5.236"/>
    <dynamics damping="0.1" friction="0.05"/>
    <safety_controller soft_lower_limit="0.05" soft_upper_limit="3.266" k_position="100" k_velocity="10"/>
  </joint>

  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
  <joint name="link3_to_link4" type="revolute">
    <origin xyz="0.00208 -0.134461 0.00412" rpy="0 0 0"/>
    <parent link="link3_1"/>
    <child link="link4_1"/>
    <axis xyz="-0.999848 0.000153 -0.017451"/>
    <limit lower="-1.658063" upper="1.658063" effort="1.5" velocity="5.236"/>
    <dynamics damping="0.1" friction="0.05"/>
    <safety_controller soft_lower_limit="-1.608" soft_upper_limit="1.608" k_position="100" k_velocity="10"/>
  </joint>

  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
  <joint name="link4_to_link5" type="revolute">
    <origin xyz="-0.01732 -0.060045 -0.000831" rpy="0 0 0"/>
    <parent link="link4_1"/>
    <child link="link5_1"/>
    <axis xyz="-1e-06 0.999961 0.008803"/>
    <limit lower="-4.276057" upper="1.570796" effort="1.5" velocity="5.236"/>
    <dynamics damping="0.1" friction="0.05"/>
    <safety_controller soft_lower_limit="-4.226" soft_upper_limit="1.521" k_position="100" k_velocity="10"/>
  </joint>

  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
  <joint name="right_clamp" type="prismatic">
    <origin xyz="-0.052134 -0.220077 -0.186037" rpy="0 0 0"/>
    <parent link="link5_1"/>
    <child link="clamp_1"/>
    <axis xyz="0.999848 -0.000154 0.017451"/>
    <limit lower="0.0" upper="0.037" effort="1.5" velocity="0.05"/>
    <dynamics damping="0.5" friction="0.1"/>
  </joint>

  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
  <joint name="left_clamp" type="prismatic">
    <origin xyz="0.072828 -0.222278 -0.183875" rpy="0 0 0"/>
    <parent link="link5_1"/>
    <child link="clamp_2"/>
    <axis xyz="0.999848 -0.000154 0.017451"/>
    <limit lower="-0.038" upper="0.0" effort="1.5" velocity="0.05"/>
    <dynamics damping="0.5" friction="0.1"/>
    <mimic joint="right_clamp" multiplier="-1" offset="0"/>
  </joint>

</robot>

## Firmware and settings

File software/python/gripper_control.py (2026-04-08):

#!/usr/bin/env python3
"""
Parallel Gripper Control Software
=================================

Professional control software for the open-source parallel gripper using
Feetech STS3215 servo motors. Provides real-time control, monitoring, and
feedback for robotics applications.

Features:
- Precise position control with degree-based input
- Real-time monitoring (position, current, voltage, temperature, load)
- Cross-platform compatibility (Windows, Linux, macOS)
- Interactive control interface
- Comprehensive error handling

Requirements:
- STServo SDK (https://github.com/FEETECH-RC/STServo_SDK_Python)
- Python 3.6+
- Serial communication interface

Author: Open-Source Parallel Gripper Project
License: MIT
"""

import logging
import os
import sys
import time
from pathlib import Path
from typing import Optional, Tuple

import serial.tools.list_ports

# Cross-platform keyboard input handling
if os.name == 'nt':
    import msvcrt
    def getch():
        """Get single character input (Windows)"""
        return msvcrt.getch().decode()
else:
    import termios
    import tty
    def getch():
        """Get single character input (Unix/Linux/macOS)"""
        fd = sys.stdin.fileno()
        old_settings = termios.tcgetattr(fd)
        try:
            tty.setraw(fd)
            return sys.stdin.read(1)
        finally:
            termios.tcsetattr(fd, termios.TCSADRAIN, old_settings)

# Graceful SDK path handling using pathlib
sdk_path = Path(__file__).resolve().parent.parent / "STservo_sdk"
sys.path.append(str(sdk_path))

try:
    from STservo_sdk import *
except ImportError:
    print("Error: STServo SDK not found!")
    print("Please install STServo SDK from: https://github.com/FEETECH-RC/STServo_SDK_Python")
    print("Copy the STservo_sdk folder to your project directory or Python path.")
    sys.exit(1)

# Dynamic COM port selection
print("\n🔌 Available COM ports:")
ports = list(serial.tools.list_ports.comports())
if not ports:
    print("❌ No COM ports found. Please connect your device and try again.")
    sys.exit(1)
for idx, port in enumerate(ports):
    print(f"  [{idx}] {port.device}")

choice = input("Select port number (default 0): ").strip()
SELECTED_PORT = ports[int(choice)].device if choice.isdigit() and int(choice) < len(ports) else ports[0].device

# Configuration Constants
class GripperConfig:
    """Configuration parameters for the parallel gripper"""

    # Servo Configuration
    STS_ID = 1                  # Servo ID (can be changed if multiple servos)
    BAUDRATE = 1000000         # Communication baud rate (1 Mbps)
    DEVICENAME = SELECTED_PORT  # Dynamic port from user selection

    # Motion Parameters
    MAX_DEGREE = 360           # Maximum rotation (degrees)
    MAX_POSITION = 4095        # Maximum position value (12-bit resolution)
    DEFAULT_SPEED = 4800       # Default movement speed
    DEFAULT_ACCELERATION = 5   # Default acceleration

    # Monitoring Parameters
    LSB_TO_mA = 2700 / 2047   # Current conversion factor (~1.32 mA per LSB)
    VOLTAGE_SCALE = 0.1       # Voltage scale factor (0.1V per LSB)
    LOAD_SCALE = 100 / 2047   # Load percentage scale factor

    # Safety Limits
    MAX_TEMPERATURE = 70      # Maximum safe temperature (°C)
    MAX_CURRENT = 2000        # Maximum safe current (mA)

    # Update Intervals
    MONITOR_INTERVAL = 0.05   # Monitoring update interval (seconds)

class ParallelGripper:
    """
    Main class for controlling the parallel gripper

    Provides high-level interface for gripper control, monitoring, and safety.
    """

    def __init__(self, config: GripperConfig = None):
        """
        Initialize the gripper controller

        Args:
            config: Configuration object (uses default if None)
        """
        self.config = config or GripperConfig()
        self.port_handler = None
        self.packet_handler = None
        self.is_connected = False

        # Setup logging
        logging.basicConfig(level=logging.INFO,
                          format='%(asctime)s - %(levelname)s - %(message)s')
        self.logger = logging.getLogger(__name__)

    def connect(self) -> bool:
        """
        Establish connection to the servo

        Returns:
            bool: True if connection successful, False otherwise
        """
        try:
            self.port_handler = PortHandler(self.config.DEVICENAME)
            self.packet_handler = sts(self.port_handler)

            if not self.port_handler.openPort():
                self.logger.error(f"Failed to open port {self.config.DEVICENAME}")
                return False

            if not self.port_handler.setBaudRate(self.config.BAUDRATE):
                self.logger.error(f"Failed to set baud rate to {self.config.BAUDRATE}")
                return False

            # Set servo to position control mode
            self.packet_handler.write1ByteTxRx(self.config.STS_ID, 33, 0)

            self.is_connected = True
            self.logger.info(f"Connected to servo ID {self.config.STS_ID} on {self.config.DEVICENAME}")
            return True

        except Exception as e:
            self.logger.error(f"Connection failed: {e}")
            return False

    def disconnect(self):
        """Close the connection to the servo"""
        if self.port_handler and self.is_connected:
            self.port_handler.closePort()
            self.is_connected = False
            self.logger.info("Disconnected from servo")

    def degrees_to_position(self, degrees: float) -> int:
        """
        Convert degrees to servo position value

        Args:
            degrees: Angle in degrees (can be negative)

        Returns:
            int: Servo position value (0-4095)
        """
        degrees = degrees % self.config.MAX_DEGREE
        return int((degrees / self.config.MAX_DEGREE) * self.config.MAX_POSITION)

    def position_to_degrees(self, position: int) -> float:
        """
        Convert servo position value to degrees

        Args:
            position: Servo position value (0-4095)

        Returns:
            float: Angle in degrees
        """
        return (position / self.config.MAX_POSITION) * self.config.MAX_DEGREE

    def move_to_angle(self, angle: float, speed: int = None, acceleration: int = None) -> bool:
        """
        Move gripper to specified angle

        Args:
            angle: Target angle in degrees
            speed: Movement speed (uses default if None)
            acceleration: Movement acceleration (uses default if None)

        Returns:
            bool: True if command sent successfully, False otherwise
        """
        if not self.is_connected:
            self.logger.error("Not connected to servo")
            return False

        speed = speed or self.config.DEFAULT_SPEED
        acceleration = acceleration or self.config.DEFAULT_ACCELERATION

        goal_position = self.degrees_to_position(angle)

        try:
            result, error = self.packet_handler.WritePosEx(
                self.config.STS_ID, goal_position, speed, acceleration
            )

            if result != COMM_SUCCESS:
                self.logger.error(f"Communication error: {self.packet_handler.getTxRxResult(result)}")
                return False

            if error != 0:
                self.logger.error(f"Servo error: {self.packet_handler.getRxPacketError(error)}")
                return False

            self.logger.info(f"Moving to {angle:.1f}° (position {goal_position})")
            return True

        except Exception as e:
            self.logger.error(f"Move command failed: {e}")
            return False

    def get_status(self) -> Optional[dict]:
        """
        Get current servo status and telemetry

        Returns:
            dict: Status information or None if error
        """
        if not self.is_connected:
            return None

        try:
            # Current position
            position, _, _ = self.packet_handler.ReadPos(self.config.STS_ID)
            degrees = self.position_to_degrees(position)

            # Current draw
            current_raw, _, _ = self.packet_handler.read2ByteTxRx(self.config.STS_ID, 69)
            current = self.packet_handler.sts_tohost(current_raw, 15)
            current_mA = current * self.config.LSB_TO_mA

            # Supply voltage
            voltage_raw, _, _ = self.packet_handler.read1ByteTxRx(self.config.STS_ID, 62)
            voltage = voltage_raw * self.config.VOLTAGE_SCALE

            # Load percentage
            load_raw, _, _ = self.packet_handler.read2ByteTxRx(self.config.STS_ID, 60)
            load_percent = int(round(load_raw * self.config.LOAD_SCALE))

            # Temperature
            temperature, _, _ = self.packet_handler.read1ByteTxRx(self.config.STS_ID, 63)

            # Movement status
            is_moving, _, _ = self.packet_handler.ReadMoving(self.config.STS_ID)

            return {
                'position': position,
                'degrees': degrees,
                'current_raw': current,
                'current_mA': current_mA,
                'voltage': voltage,
                'load_percent': load_percent,
                'temperature': temperature,
                'is_moving': bool(is_moving)
            }

        except Exception as e:
            self.logger.error(f"Status read failed: {e}")
            return None

    def wait_for_completion(self, target_position: int, timeout: float = 10.0) -> bool:
        """
        Wait for movement to complete with real-time monitoring

        Args:
            target_position: Expected final position
            timeout: Maximum wait time in seconds

        Returns:
            bool: True if movement completed successfully
        """
        start_time = time.time()

        print("🟡 Movement in progress... (Press Ctrl+C to stop)\n")

        try:
            while time.time() - start_time < timeout:
                time.sleep(self.config.MONITOR_INTERVAL)

                status = self.get_status()
                if not status:
                    return False

                # Display status
                print(f" → Target: {target_position:4d} | "
                      f"Position: {status['position']:4d} ({status['degrees']:6.1f}°) | "
                      f"Current: {status['current_raw']:3d} ({status['current_mA']:.0f}mA) | "
                      f"Load: {status['load_percent']:2d}% | "
                      f"Temp: {status['temperature']}°C")

                # Safety checks
                if status['temperature'] > self.config.MAX_TEMPERATURE:
                    self.logger.warning(f"High temperature: {status['temperature']}°C")

                if status['current_mA'] > self.config.MAX_CURRENT:
                    self.logger.warning(f"High current: {status['current_mA']:.0f}mA")

                # Check if movement completed
                if not status['is_moving']:
                    print("✅ Movement completed\n")
                    return True

            self.logger.warning("Movement timeout")
            return False

        except KeyboardInterrupt:
            print("\n⏹️ Movement interrupted by user")
            return False

    def interactive_control(self):
        """Run interactive control interface"""
        print("\n" + "="*60)
        print("🤖 PARALLEL GRIPPER CONTROL INTERFACE")
        print("="*60)
        print(f"Servo ID: {self.config.STS_ID}")
        print(f"Port: {self.config.DEVICENAME}")
        print(f"Baud Rate: {self.config.BAUDRATE}")
        print("-"*60)
        print("Commands:")
        print("  • Enter angle in degrees (positive or negative)")
        print("  • Press Enter (empty) to exit")
        print("  • Ctrl+C to interrupt movement")
        print("="*60)

        try:
            while True:
                user_input = input("\nEnter target angle (degrees): ").strip()

                if not user_input:
                    print("👋 Exiting...")
                    break

                try:
                    angle = float(user_input)
                    target_position = self.degrees_to_position(angle)

                    if self.move_to_angle(angle):
                        self.wait_for_completion(target_position)

                except ValueError:
                    print("❌ Invalid input. Please enter a number.")
                except Exception as e:
                    self.logger.error(f"Control error: {e}")

        except KeyboardInterrupt:
            print("\n👋 Control interface interrupted")

def main():
    """Main function - entry point for the application"""
    print("🚀 Starting Parallel Gripper Control Software...")

    # Create gripper instance
    gripper = ParallelGripper()

    try:
        # Connect to servo
        if not gripper.connect():
            print("❌ Failed to connect to servo. Please check:")
            print("  • Port name (currently: {})".format(gripper.config.DEVICENAME))
            print("  • Servo power and connections")
            print("  • Servo ID (currently: {})".format(gripper.config.STS_ID))
            print("  • Baud rate (currently: {})".format(gripper.config.BAUDRATE))
            return 1

        # Run interactive control
        gripper.interactive_control()

    except Exception as e:
        print(f"❌ Unexpected error: {e}")
        return 1

    finally:
        # Ensure clean shutdown
        gripper.disconnect()

    return 0

if __name__ == "__main__":
    sys.exit(main())

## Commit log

2026-02-14 docs: Add Parallel Gripper product spec PDF, update SO-ARM101 spec PDF, and add links across documentation
2026-02-14 docs: Update gripper specs from product specification PDF and add new media assets
2026-02-14 docs: Remove outdated dimension and camera images, update references to new assets
2026-02-14 docs: Update BOM rods, hardware requirements, and dimension naming to match developer README
2026-02-14 docs: Update README to reflect the integration of the gripper with SO-ARM101, including image and description changes
2026-03-31 Update assembly-guide
2026-03-31 picture for Camera Holder and Holder
2026-03-31 deleted old stl models
    [Follower_Gripper_180x180_BedSize.STL, RB9.01.060.015 Main frame 128mm (follower).STL, RB9.01.060.021 Clamp.STL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]
2026-03-31 step and stl all-in-one
    [Follower gripper (140x140 bed size).STL]
2026-04-07 feat: add multi-simulator ROS2 support (Gazebo, MuJoCo, Webots, CoppeliaSim, Isaac Sim)
    Add a complete ROS2 description package with a single parameterized URDF
    that drives 5 physics engines through one launch file.
    - simulation/so_arm_101_description/: full ROS2 package with URDF, meshes,
    controllers, launch files, Dockerfile, and docker-compose
    - Per-simulator READMEs with setup guides, launch instructions, and
    troubleshooting for each backend
    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
    [base_link.stl, clamp_1.stl, clamp_2.stl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]
2026-04-08 chore: add CI/CD pipeline and pre-commit hooks
    - Add GitHub Actions CI with lint, validate, URDF, and test jobs
    - Add .pre-commit-config.yaml (flake8, isort, trailing whitespace, XML)
    - Fix isort import order in simulation launch files
    - Fix trailing whitespace in docs and existing files
    [gripper_control.py]
2026-05-10 removed linear bearings
2026-05-11 Update2 bom.md
2026-05-11 Update3 bom.md
2026-05-13 new assembly pictures
2026-05-13 stl and step for gripper
    [Follower gripper (165x165 bed size).STL, RB9.01.062.000 Gripper.STEP]
2026-05-13 stl for parts
    [RB9.01.060.074 Camera holder.STL, RB9.01.060.080 Holder.STL, RB9.01.060.090 Camera spacer.STL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]
2026-05-13 deleted old stl files
    [Follower gripper (140x140 bed size).STL, RB9.01.061.000 Gripper.STEP, RB9.01.061.010 Main frame.STL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]
2026-05-13 Fix trailing whitespace in assembly guide
2026-05-19 docs: replace main README image with new gripper photo
2026-05-19 docs: update video link to new gripper demo and sync quick-start image
2026-05-20 docs: replace main README image with new gripper photo
    Swap assets/images/SO-ARM-101-Parallel-Gripper.jpg for a new PNG
    and update references in README.md and docs/quick-start.md.
2026-06-01 just one rod
2026-06-23 stl for D405 Holder
    [RB9.01.060.110 D405 holder.STL]
2026-06-23 update 3 cameras picture
2026-06-23 clamps stl files with holes 6.0-6.3
    [Gripper test plate star holes 6.0-6.3.STL, RB9.01.062.021 (D6.0) Clamp.STL, RB9.01.062.021 (D6.1) Clamp.STL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]
2026-06-23 assembly-guide.md with nails
2026-06-23 added test plate usage in README.md
2026-06-23 added test plate to quick-start.md
2026-06-23 deleted old rods+clamps.png

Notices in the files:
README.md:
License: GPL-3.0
